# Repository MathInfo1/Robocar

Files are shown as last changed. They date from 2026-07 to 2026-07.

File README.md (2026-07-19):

# Robocar
A simple 3D-printed cylindrical robocar, that can follow a fixed path or can be remote controlled. It is controlled by an Arduino Uno and uses batteries or a powerbank. 



## What does it do?
The robot can follow either follow a fixed path or be remote controlled. Example code including functions for a fixed path are given. There is also a code with which you can manually control the robot with the remote. It only moves if you press the arrow keys, but you can also press some buttons to make it follow a fixed path. The robot can be coded as wanted. 
</br></br>
Demo 1 (Fixed path): https://youtu.be/czfSZnnJx2o </br>
Demo 2 (Remote-controlled): https://www.youtube.com/shorts/nxYcud6KOsA

## Parts required
- 3D-printed parts
- Arduino (Uno) + cable
- Breadboard if wanted
- rubber or similar if wanted (to increase friction of wheels)
- 2 TT gear motors
- 1 Metal Ball Caster
- 2 screws
- TB6612FNG Dual Driver
- Infrared Remote and Sensor
- Batteries (~6V and enough current supply) or Powerbank
- Cylindrical Magnets (6x2mm)
- Jumper wires or similar



## Steps to reproduce
### Print parts
If you want my default settings (dimensions set such that Creality CR-10 SE can print it), just download all 4 .3mf-files, slice it and print. Dimensions are 200x200x60mm. </br>
If you want to make some adjustments, first download Robocar 1.FCStd (FreeCAD). You can adjust many things through the variables in VarSet. The wheels and wheel axis need to be edited manually as they do not use the variables. Just make sure there is enough gap to enter the wheel from the top. Then export the files, slice and print. </br>
You need to print 2 wheels and 2 wheel axes. You need only one each of the main body and lid. 



### Assembly
If wanted, add rubber (or anything that increases friction) around the wheels. Insert the wheels from the top and fix them with the axis. Stick it with glue if everything else works. Attach the motors from the inside, making them face outwards, so there's place in the center to place a breadboard/powerbank/batteries/etc. </br>
In the back insert the ball caster and fasten it with screws. </br>
Place the Arduino between the motors such that the cable can be inserted from the center. </br> 
Put 2 magnets in each slot on the main body and 1 magnet per slot in the lid. </br>
If everything seems fine, then fix the wheel axis to the wheel with glue. Fix the motors in place, for example with double-sided tape. It's also a good idea to fix other things like Arduino and breadboard, but it isn't required. Then solder all the parts according to the schematics. Make sure the lid fits on top and has enough force. 

### Software
Download the Arduino files and open the wanted one. You can edit the code as wanted. Use the Arduino cable to connect the Arduino Uno with the PC and upload. For the remote-controlled code, you need to install the IRremote package and replace the button codes (hex values) with those of your remote. Check the codes in the Serial Monitor. </br>
<b>Warning: The fixed path code makes the wheels rotate immediatly, so make sure they aren't touching the floor when uploading the program. </b></br>
After uploading, disconnect from PC and connect to batteries / powerbank. To restart the code, press the reset button on the Arduino. 

### Code Changes
You can create your own paths as you want, feel free to use my functions. My driver didn't have the PWM pins, so I just used digitalWrite, so the wheels always went in maximum speed (I could have still used analogWrite, but it wasn't as reliable as the PWM pins). If you have the PWM pins, connect them to the Arduino and you can control the wheel speed with it, allowing you to write much cooler programs! 

## AI Use
I used some AI to get decide which motors, sensors, etc. to use. I compared multiple suggestions and picked what I found best. The code was written by me, but about 1-2 times I was stuck and asked ChatGPT why it didn't work (it turned out to be a hardware issue).

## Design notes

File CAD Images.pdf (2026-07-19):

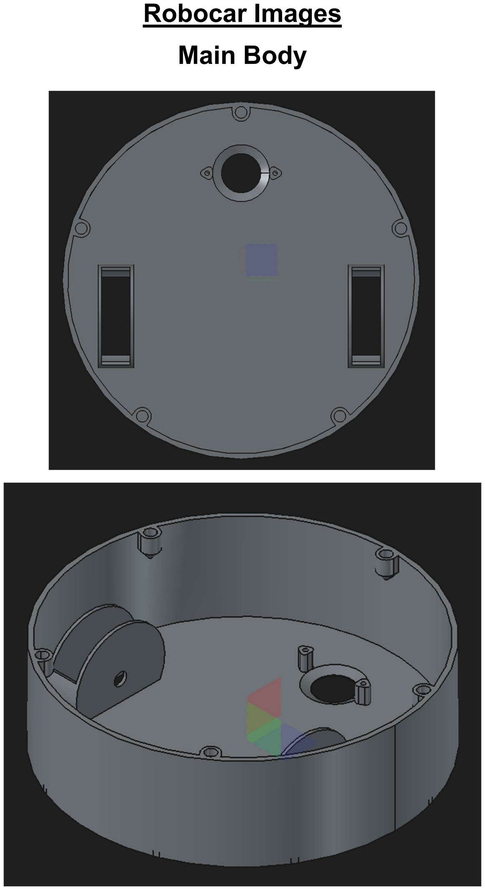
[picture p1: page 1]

Robocar Images
Main Body

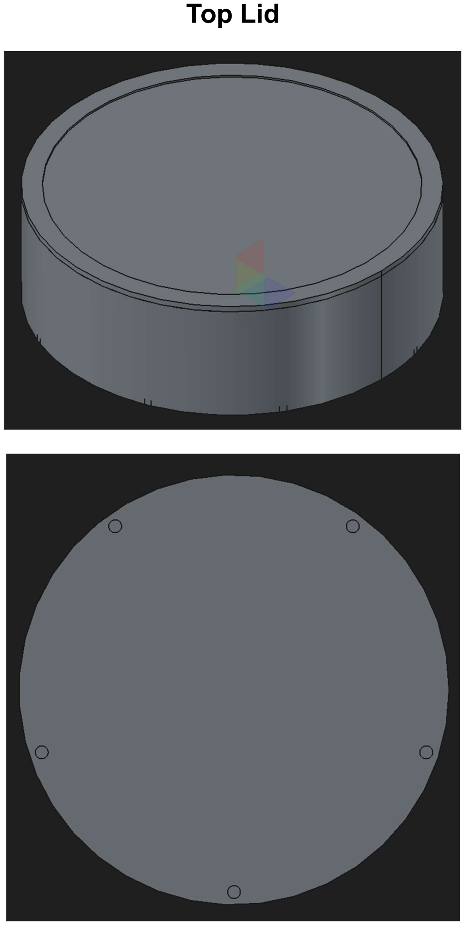
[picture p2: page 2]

Top Lid

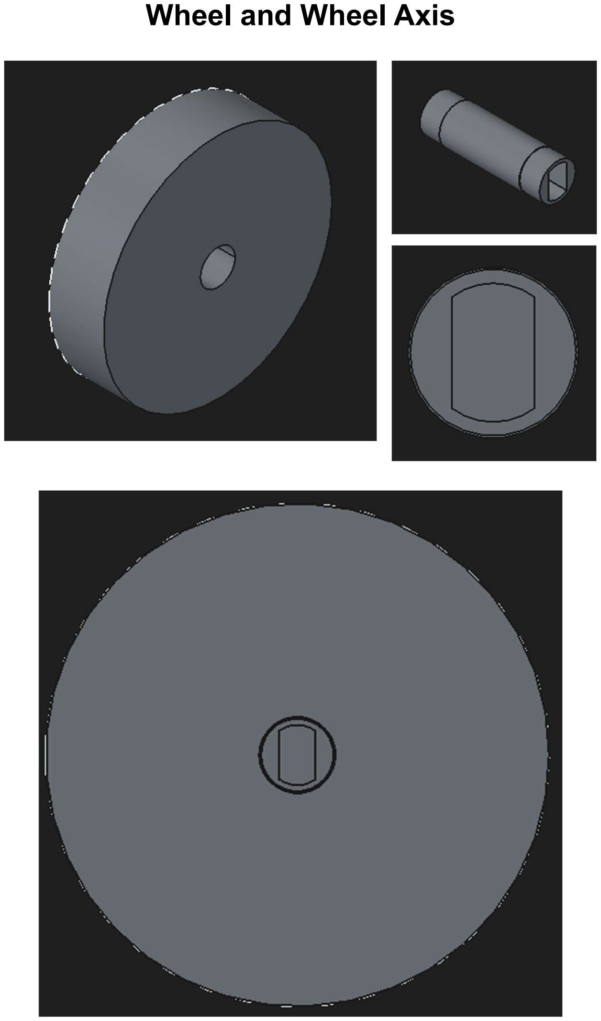
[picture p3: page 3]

Wheel and Wheel Axis

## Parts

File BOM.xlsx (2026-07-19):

Item | Link / Info | Cost per Part | Count | Total Cost
Robocar 3D printed parts | 20% infill density, default settings | ~ $ 10 | 1 | $10.00
Arduino Uno R3 + Arduino Cable + Jumper cables/… |  | ~ $ 30 | 1 | $30.00
AA Alkaline Batteries (for 5V supply + high current) | Alternative: Li-ion batteries, powerbank, ... | ~ $ 0.50 | 4 | $2.00
TT Gear Motor (1:48 or any) | https://www.amazon.de/RUNCCI-YUN-DC3V-6V-Micro-Motor-Arduino/dp/B09TDF1HY9 | ~ $ 1.25 | 2 | $2.50
TB6612FNG Dual Driver | Much cheaper if bought in set | ~ $ 3 | 1 | $3.00
Metal Ball Caster + 2 screws (M3x8) | https://www.robotshop.com/products/metal-ball-caster | ~ $ 2.50 | 1 | $2.50
Strong Cylindrical Magnets (6x2mm) |  | ~ $ 0.03 | ~ 15 | $0.50
IR-Remote + Receiver |  | ~ $ 2 | 1 | $2.00
Total |  |  |  | $52.50

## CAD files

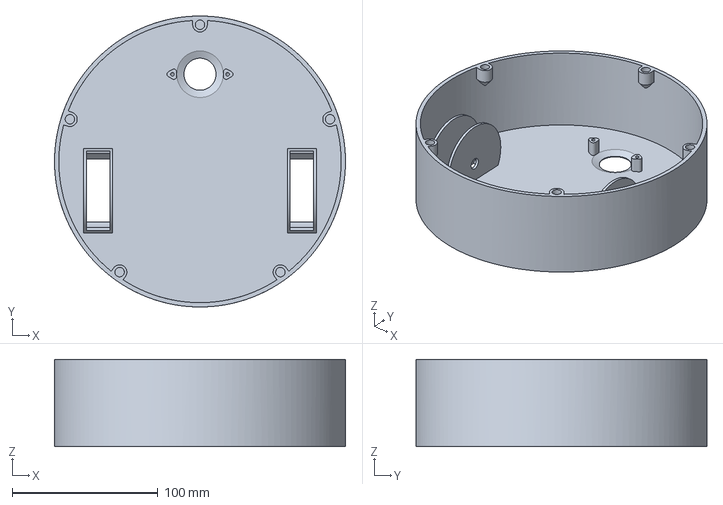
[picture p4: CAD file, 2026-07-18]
Main Body.3mf
200.0 x 199.9 x 60.0 mm

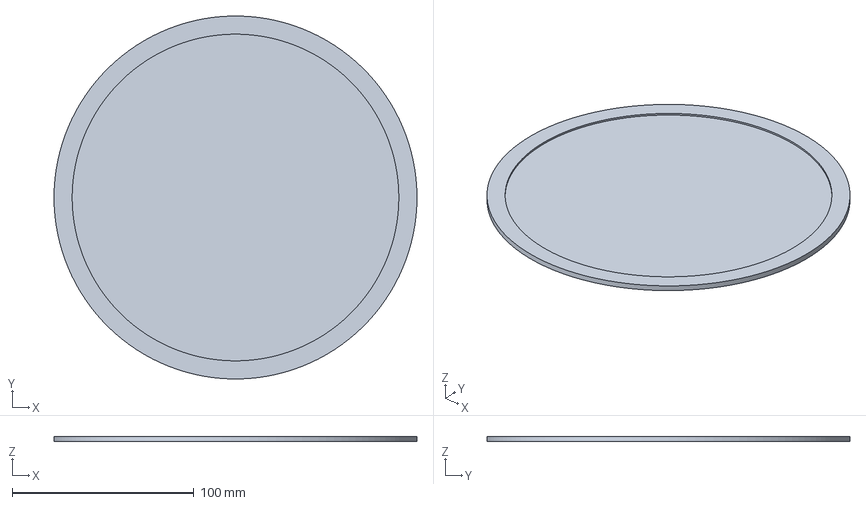
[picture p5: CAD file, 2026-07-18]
Top Lid.3mf
200.0 x 199.9 x 3.00 mm

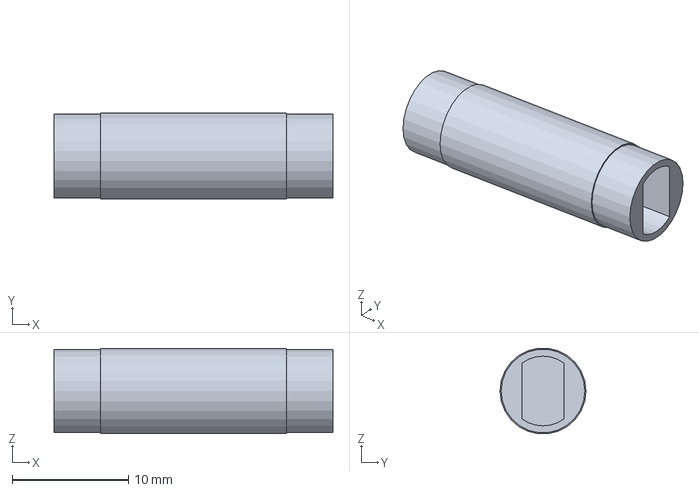
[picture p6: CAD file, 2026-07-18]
Wheel Axis.3mf
24.0 x 7.40 x 7.35 mm

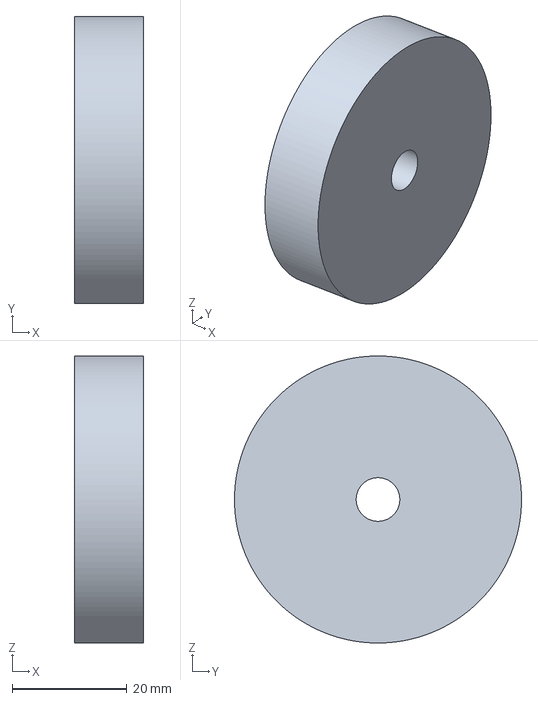
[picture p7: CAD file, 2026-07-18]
Wheel.3mf
12.0 x 50.0 x 50.0 mm

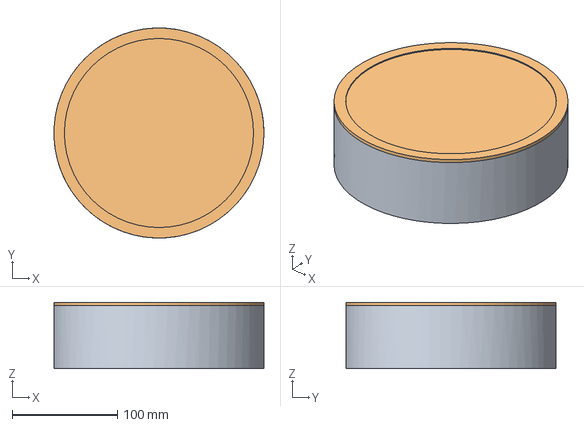
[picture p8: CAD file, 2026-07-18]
Robocar 1.FCStd
199.9 x 199.9 x 63.0 mm
Main Body
Top Lid

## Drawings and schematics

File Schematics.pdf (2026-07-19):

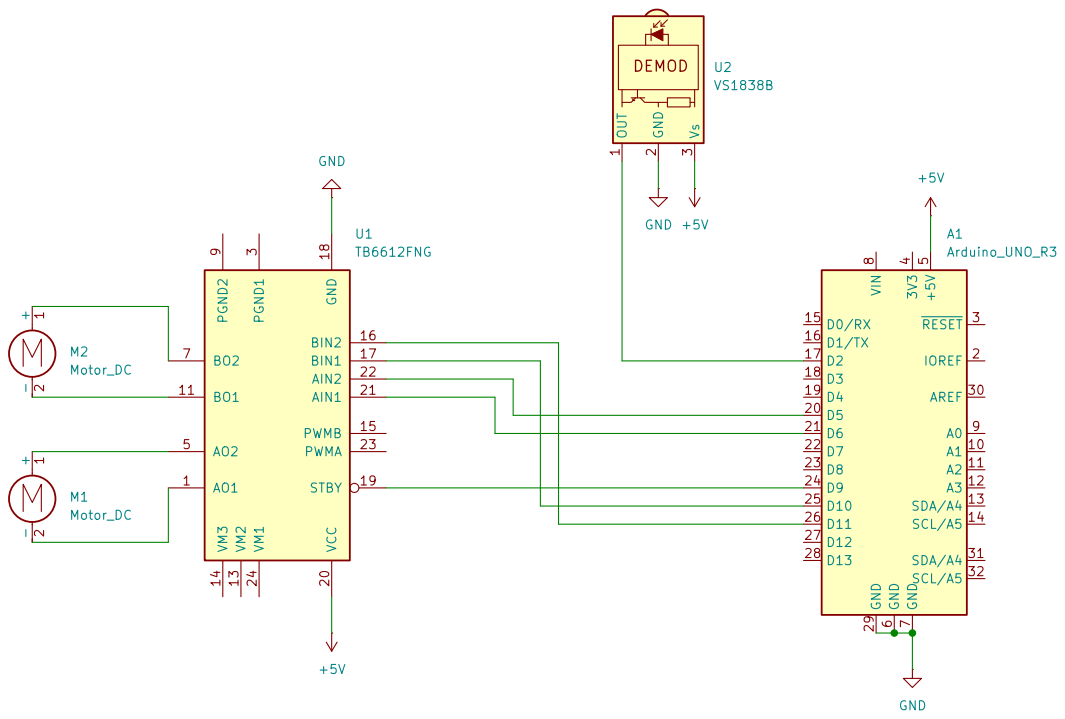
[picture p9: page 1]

Size: A4 | Rev:
KiCad E.D.A. 10.0.3 | Id: 1/1

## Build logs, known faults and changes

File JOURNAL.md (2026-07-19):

# Journal
## 12/06/2026: Modelling </br>
https://lapse.hackclub.com/timelapse/ffJD8ZTb1KVO </br>
I started modelling the robocar in FreeCAD. I probably took longer than others since it was my first time using FreeCAD (after a short tutorial). 

## 13/06/2026: Modelling </br>
https://lapse.hackclub.com/timelapse/cmpgJl__rkQP </br>
I continued modelling the robocar. 

## 14/06/2026: Modelling </br>
https://lapse.hackclub.com/timelapse/cJIqRPy--OlX </br>
I continued modelling the robocar. 

## 15/06/2026: Modelling </br>
https://lapse.hackclub.com/timelapse/jXTJ5bqY9P_r </br>
I continued modelling the robocar and also started with the printing. 

## 17/06/2026: Software </br>
https://lapse.hackclub.com/timelapse/t2v3nSfvFEeK </br>
Since I never controlled DC motors with a driver before, I tried writing simple programs and testing them. 

## 18/06/2026: Modelling + Building </br>
https://lapse.hackclub.com/timelapse/7Cxx_Segv7LY </br>
https://lapse.hackclub.com/timelapse/HRwR_0iOnyde </br>
I made some mistakes in the modelling of the wheels, so I couldn't connect them to the main body. So I tried remodelling them till it worked. 
Since I already had a few failed prints, I make a connector to the wheel axis and wheel. 
Later I made the correct version of the wheels, so you don't need the connector

https://lapse.hackclub.com/timelapse/ZxdzaBbLhhu- </br>
Here's me assembling the parts and soldering the second motor. I didn't record the entire assembly, like the soldering of the first motor. 

## 12/07/2026: Software </br>
https://lapse.hackclub.com/timelapse/meEvZ34J-O01 </br>
I tried writing a functioning program that follows a fixed path. However even though I spent a lot of time off screen before that, 
I couldn't find the reason to why the motors couldn't switch direction (the could turn either way if started in that direction). 

## 14/07/2026: Building </br>
https://lapse.hackclub.com/timelapse/PdOaCu7m3qEc </br>
Since the motors kept coming off and the magnets weren't attached yet, I attached them to the robocar now. 

## 16/07/2026: Software </br>
https://lapse.hackclub.com/timelapse/yU_JiVVKPK9g </br>
I now found out the problem (used ChatGPT, it was the current). I then wrote a program that finally worked (see Demo 1)!

## 19/06/2026: Software + Schematics </br>
https://lapse.hackclub.com/timelapse/mrTAsF2jXjFi </br>
I tested the IR remote for the first time and attached it to the robocar. I then wrote a new program and tested it till it worked (see Demo 2)! 

https://lapse.hackclub.com/timelapse/CJDD1NlOU-yL </br>
I created the schematics for the circuit with KiCAD (first time doing this as well). I also saved images of the CAD model as a PDF. 

# Extra Info
Here's the entire Project with all recordings: https://hackatime.hackclub.com/my/projects/Robocar%201

I spent a lot of time off screen trying to fix the code / CAD model because I thought it would be marked as fraud, etc. I just hope that it balances any 
time reduction for other things. Also in the software recordings, I tested it directly to make sure it works as I have never done a big hardware project 
like this on my own before.

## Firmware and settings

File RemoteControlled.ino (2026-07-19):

#include<IRremote.hpp>

int STBY = 9;
int AIN1 = 6;
int AIN2 = 5;
int BIN1 = 10;
int BIN2 = 11;
int IRpin = 2;
int resetTime = 500;

String action = "";

void reset(bool timeReset = false) {
  action = "reset";
  digitalWrite(AIN1, LOW);
  digitalWrite(AIN2, LOW);
  digitalWrite(BIN1, LOW);
  digitalWrite(BIN2, LOW);
  digitalWrite(STBY, HIGH);
  // if (timeReset) timeStart = millis();
}

void forward() {
  reset();
  delay(resetTime);
  action = "forward";
  digitalWrite(AIN1, HIGH);
  digitalWrite(AIN2, LOW);
  digitalWrite(BIN1, LOW);
  digitalWrite(BIN2, HIGH);
}

void backward() {
  reset();
  delay(resetTime);
  action = "backward";
  //Serial.println(action);
  digitalWrite(AIN1, LOW);
  digitalWrite(AIN2, HIGH);
  digitalWrite(BIN1, HIGH);
  digitalWrite(BIN2, LOW);
}

void left() {
  reset();
  delay(resetTime);
  action = "left";
  digitalWrite(AIN1, HIGH);
  digitalWrite(AIN2, LOW);
  digitalWrite(BIN1, HIGH);
  digitalWrite(BIN2, LOW);
}

void right() {
  reset();
  delay(resetTime);
  action = "right";
  digitalWrite(AIN1, LOW);
  digitalWrite(AIN2, HIGH);
  digitalWrite(BIN1, LOW);
  digitalWrite(BIN2, HIGH);
}


void setup() {
  pinMode(AIN1, OUTPUT);
  pinMode(AIN2, OUTPUT);
  pinMode(BIN1, OUTPUT);
  pinMode(BIN2, OUTPUT);
  pinMode(STBY, OUTPUT);
  Serial.begin(9600);
  IrReceiver.begin(IRpin, ENABLE_LED_FEEDBACK);
}

void loop() {
  // put your main code here, to run repeatedly:
  if (IrReceiver.decode()) {
    //Serial.println(IrReceiver.decodedIRData.decodedRawData, HEX);
    IrReceiver.printIRResultShort(&Serial);
    // if (IrReceiver.decodedIRData.decodedRawData == 0xE31CFF00) action = "stop";
    // else if (IrReceiver.decodedIRData.decodedRawData == 0xE718FF00) action = "forward";
    // else if (IrReceiver.decodedIRData.decodedRawData == 0xAD52FF00) action = "backward";
    // else if (IrReceiver.decodedIRData.decodedRawData == 0xF708FF00) action = "left";
    // else if (IrReceiver.decodedIRData.decodedRawData == 0xA55AFF00) action = "right";
    if (IrReceiver.decodedIRData.decodedRawData == 0xE31CFF00) reset();
    else if (IrReceiver.decodedIRData.decodedRawData == 0xE718FF00) forward();
    else if (IrReceiver.decodedIRData.decodedRawData == 0xAD52FF00) backward();
    else if (IrReceiver.decodedIRData.decodedRawData == 0xF708FF00) left();
    else if (IrReceiver.decodedIRData.decodedRawData == 0xA55AFF00) right();
    Serial.println(action);
    IrReceiver.resume();
  }
}

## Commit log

2026-07-18 Added Final Version of CAD-File
    [Robocar 1.FCStd]
2026-07-18 All final exported as (3mf) files
    [Main Body.3mf, Top Lid.3mf, Wheel Axis.3mf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]
2026-07-18 Added Fixed Path
    Works at my home or any open place (long path). It is the path showed in the Demo1-Video.
    [FixedPath.ino]
2026-07-19 Added Schematics and CAD images
2026-07-19 Added BOM
    [BOM.xlsx]
